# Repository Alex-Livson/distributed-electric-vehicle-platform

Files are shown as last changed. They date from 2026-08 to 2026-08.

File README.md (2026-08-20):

# Distributed Electric Vehicle Control and Autonomy Platform

A small-scale electric vehicle electronics platform built around **three custom ESP32-based ECUs and a Raspberry Pi 4 supervisory controller**, connected through a **500 kbps CAN network**.

The project was built as a hands-on study of automotive embedded systems, custom PCB design, distributed vehicle electronics, safety-oriented control, Raspberry Pi development, and computer vision.

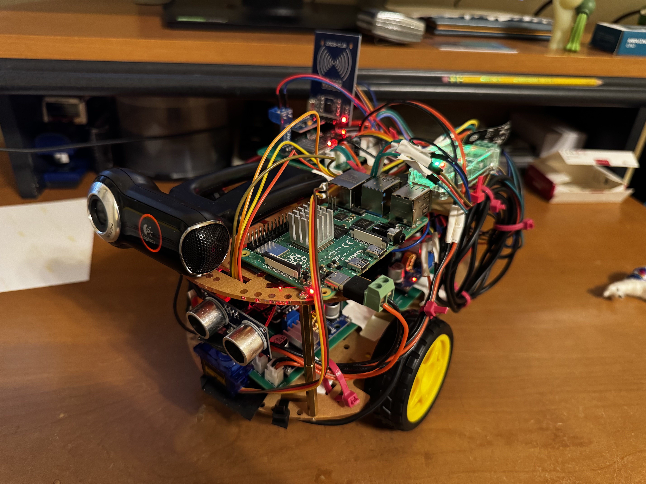
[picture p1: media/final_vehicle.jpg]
Final Vehicle


## Demo

[Watch the Vehicle Demo](https://youtu.be/MoWJwQRdX8E)

The demonstration includes manual driving, RFID authorization, assisted collision protection, live vehicle telemetry, and OpenCV-assisted autonomous obstacle avoidance.

---

## Project Overview

The vehicle uses a distributed control architecture similar in concept to a simplified electric vehicle.

Instead of one microcontroller handling the entire system, responsibilities are divided between several networked controllers:

* **Battery ECU** – monitors pack voltage, current, temperature, and battery health
* **Sensor ECU** – manages ultrasonic ranging, servo scanning, IMU telemetry, RFID authorization, OLED displays, and the LED matrix
* **Motor ECU** – controls the left and right drive motors
* **Raspberry Pi 4** – acts as the supervisory vehicle computer, hosts the dashboard, manages safety logic, processes CAN telemetry, and runs OpenCV perception

All four nodes communicate over a shared **500 kbps CAN bus**.

---

## Key Features

* Three custom ESP32 ECU PCBs designed in KiCad
* Four-node 500 kbps CAN network
* Raspberry Pi 4 supervisory vehicle controller
* Browser-based real-time vehicle dashboard
* Manual, Assisted, and Autonomous driving modes
* Whole-vehicle voltage, current, and temperature monitoring
* RFID-based vehicle authorization
* Ultrasonic obstacle detection with servo scanning
* OpenCV-assisted autonomous obstacle avoidance
* IMU acceleration, angular velocity, and orientation telemetry
* Differential motor control
* Emergency-stop functionality
* CAN and browser communication watchdogs
* Distance-based collision protection
* Multi-stage overcurrent protection
* Automatic Raspberry Pi and CAN startup

---

# System Architecture

The architecture separates sensing, power monitoring, motor actuation, and higher-level decision making.

```text
                         Raspberry Pi 4
                    Supervisory Vehicle Computer
                              │
                              │
                       500 kbps CAN Bus
                              │
          ┌───────────────────┼───────────────────┐
          │                   │                   │
     Battery ECU          Sensor ECU          Motor ECU
          │                   │                   │
     INA228 + NTC      Ultrasonic / IMU       TB6612FNG
                            RFID             Dual TT Motors
                         OLED Displays
                          LED Matrix
```

The Raspberry Pi receives telemetry from each ECU, applies supervisory safety rules, and transmits the final motor commands to the vehicle.

---

# Custom ECU Hardware

The electronics were first validated on breadboards and then converted into three custom two-layer PCBs.

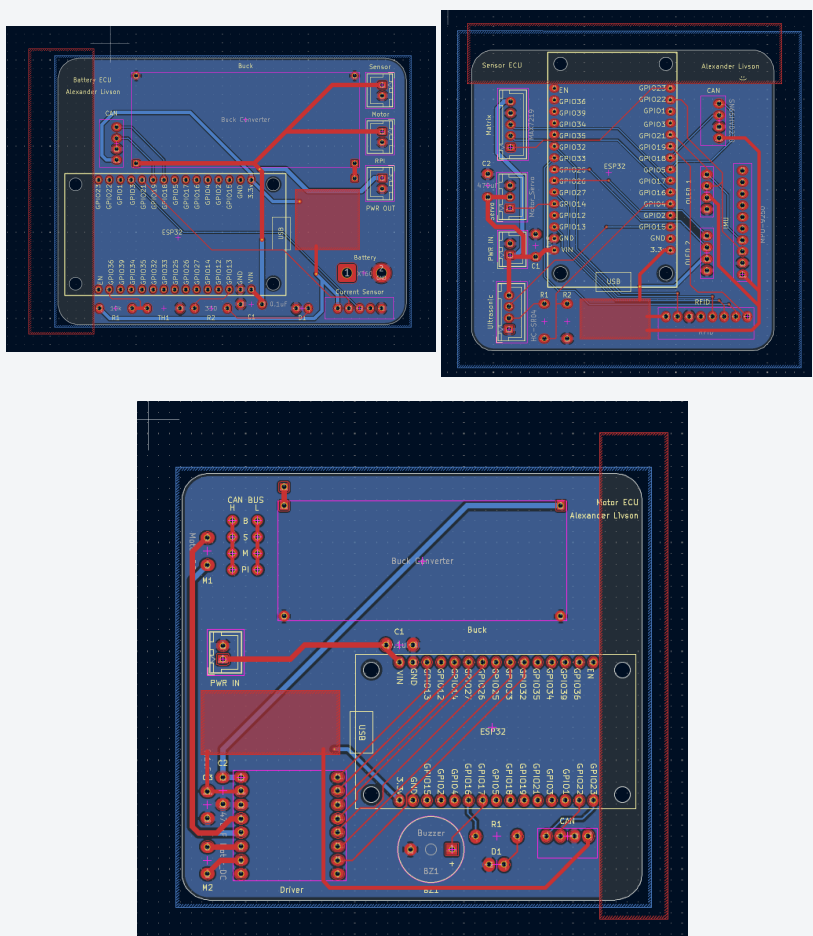
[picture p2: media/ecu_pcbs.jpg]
ECU PCBs


## Battery ECU

The Battery ECU monitors the electrical health of the complete vehicle.

Hardware includes:

* ESP32-WROOM-32 development board
* INA228 current and voltage monitor
* 10 kΩ NTC thermistor
* CAN transceiver
* Status LED
* Power-distribution connections

The INA228 is positioned near the beginning of the vehicle power path so current measurement represents the entire system.

---

## Sensor ECU

The Sensor ECU manages most of the vehicle's environmental sensing and local user interface.

It controls:

* HC-SR04 ultrasonic distance sensor
* Microservo for left/center/right scanning
* MPU9250 IMU
* MFRC522 RFID reader
* Two 0.96" 128×64 OLED displays
* MAX7219 8×8 LED matrix
* CAN communication

The ultrasonic sensor continuously provides forward and directional range data used by both the safety system and autonomous driving logic.

---

## Motor ECU

The Motor ECU controls two TT gearmotors through a **TB6612FNG dual motor driver**.

Commands are transmitted as independent signed left and right motor percentages, allowing:

* Forward driving
* Reverse driving
* Differential steering
* In-place turning

The ECU also reports motor status back to the Raspberry Pi over CAN.

---

# PCB Development

All three ECU boards were designed in **KiCad**.

The PCB development process included:

1. Breadboard hardware validation
2. Schematic capture
3. Custom through-hole footprint creation
4. Two-layer PCB layout
5. Ground-plane design
6. Power trace sizing
7. ESP32 antenna keep-out
8. Design Rule Check
9. Fabrication through JLCPCB
10. Hand soldering and hardware bring-up

Typical trace widths were approximately:

* **0.25 mm** for signals
* **0.75 mm** for 3.3 V distribution
* **1.0 mm** for higher-current 5 V paths

The bottom layer was used primarily as a ground plane.

---

# CAN Network

The completed vehicle contains four CAN nodes operating at **500 kbps**.

The Battery ECU and Raspberry Pi are located at the two ends of the physical bus and provide termination.

A powered-off measurement across CAN-H and CAN-L is approximately **60 Ω**, corresponding to two effective 120 Ω terminating resistors.

## CAN Message Map

| CAN ID  | Direction | Purpose |
| --- | --- | --- |
| `0x100` | Battery ECU → Pi | Battery voltage, current, and temperature |
| `0x200` | Sensor ECU → Pi  | Sensor status, ultrasonic range, RFID state |
| `0x201` | Sensor ECU → Pi  | Accelerometer X/Y/Z |
| `0x202` | Sensor ECU → Pi  | Angular velocity X/Y/Z |
| `0x203` | Sensor ECU → Pi  | Roll, pitch, and yaw |
| `0x204` | Sensor ECU → Pi  | Left, center, and right ultrasonic ranges |
| `0x300` | Motor ECU → Pi | Motor output and ECU status |
| `0x400` | Pi → Vehicle | Drive command, mode, speed limit, and safety state |
| `0x401` | Pi → Sensor ECU  | Lock/unlock request |

Detailed CAN payload definitions are available in the full engineering report.

---

# Raspberry Pi Vehicle Computer

The vehicle computer is a **Raspberry Pi 4 Model B with 1 GB RAM** running Raspberry Pi OS Lite.

The main controller is written in Python and integrates:

* Linux SocketCAN
* Flask
* OpenCV
* Threaded CAN reception
* Safety management
* Vehicle state tracking
* Autonomous decision making
* Browser control
* Camera streaming

The Pi runs a supervisory control loop every **20 ms**, corresponding to approximately **50 Hz**.

CAN and the main vehicle application are configured to initialize automatically when the Raspberry Pi boots.

---

# Web Dashboard

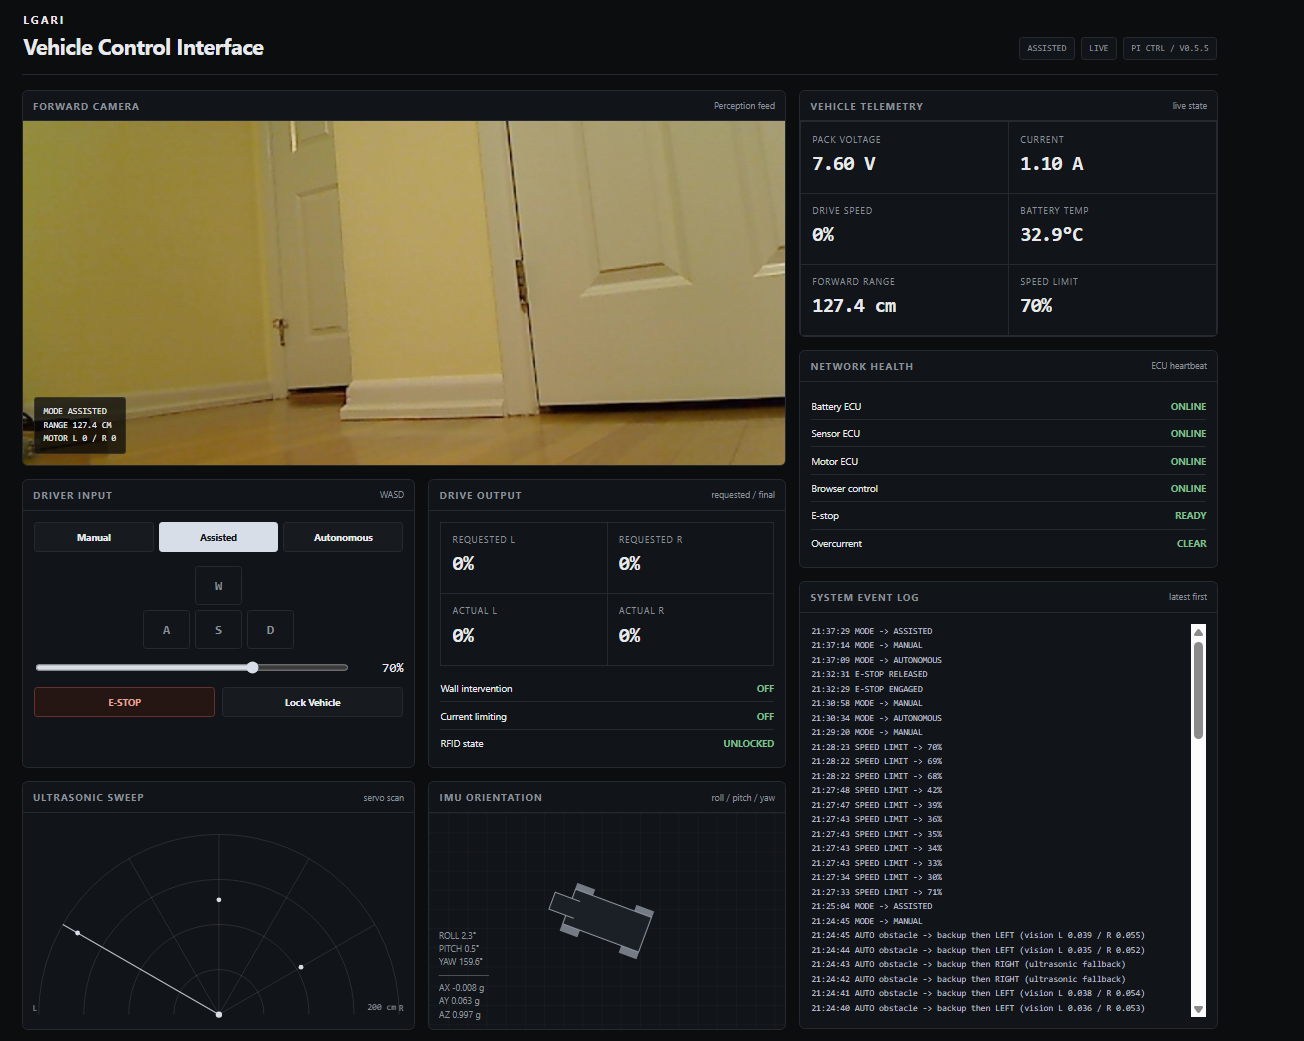
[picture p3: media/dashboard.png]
Vehicle Dashboard


The Raspberry Pi hosts a local browser-based vehicle interface.

The dashboard displays:

* Live forward camera
* Drive mode
* Motor requests and feedback
* Pack voltage
* Pack current
* Battery temperature
* Ultrasonic distance
* Ultrasonic radar visualization
* IMU orientation
* Acceleration
* ECU network health
* RFID lock state
* E-stop state
* Current limiting
* Wall intervention
* System event history

Manual and Assisted driving are controlled using **WASD**, with an adjustable 0–100% speed limit.

---

# Drive Modes

## Manual

Manual mode gives the driver direct WASD control over the differential drive system.

A forward collision stop remains active even in Manual mode so the vehicle cannot continue driving directly into a very close obstacle during testing.

---

## Assisted

Assisted mode keeps manual WASD control while adding distance-based collision protection.

| Forward Distance | Vehicle Response |
| --- | --- |
| Greater than 40 cm | Normal requested output |
| 20–40 cm | Forward output progressively reduced |
| 12–20 cm | Positive forward commands removed |
| Less than 12 cm | Hard forward collision intervention  |

This allows the driver to remain in control while the supervisory system limits unsafe commands.

---

## Autonomous

Autonomous mode combines **ultrasonic ranging and OpenCV computer vision**.

The ultrasonic sensor determines when an obstacle is physically close.

When an obstacle requires avoidance, OpenCV evaluates the left and right portions of the camera image to estimate which side appears less obstructed.

The vehicle then:

1. Detects the obstacle
2. Determines the clearer direction
3. Reverses briefly to create turning clearance
4. Turns toward the clearer side
5. Resumes forward driving

If the camera result is unavailable or nearly tied, the vehicle falls back to the left/right ultrasonic scan.

The system is intended as **vision-assisted obstacle avoidance**, rather than full autonomous driving or localization.

---

# OpenCV Perception

The OpenCV pipeline processes the lower portion of the forward camera image.

Processing includes:

* Grayscale conversion
* Gaussian blur
* Canny edge detection
* Edge dilation
* Left/right image segmentation
* Weighted edge-density comparison

The lower portion of each image region is weighted more heavily because it is more likely to contain obstacles in the vehicle's immediate path.

---

# Safety Architecture

All requested motor commands pass through a supervisory safety manager before being transmitted to the Motor ECU.

| Protection | Behavior |
| --- | --- |
| RFID authorization | Blocks vehicle movement while locked |
| Emergency stop | Overrides all drive modes |
| Browser watchdog | Stops Manual/Assisted control after 500 ms without fresh input |
| Battery ECU timeout  | Blocks motion if critical battery telemetry becomes stale |
| Sensor ECU timeout | Blocks motion if critical sensor telemetry becomes stale |
| Wall protection | Slows or stops forward movement near obstacles |
| Current warning | Reduces motor output above 4.75 A |
| Current limiting | Stronger output reduction above 5.25 A |
| Overcurrent shutdown | Stops vehicle above 5.50 A and applies a 1.5 s cooldown |

The system follows a fail-safe principle: if the controller does not have enough current information to determine that movement is safe, the preferred state is no movement.

---

# Final System Performance

| Metric | Result |
| --- | --- |
| CAN bitrate | 500 kbps |
| Pi supervisory loop | 50 Hz |
| Local browser control latency | ~20–30 ms |
| Idle current | ~0.8–0.9 A |
| Typical driving current | ~1.2–1.3 A |
| Peak observed current | ~1.6 A |
| Battery runtime | ~1 hour |
| Battery | 2S 7.4 V, 2000 mAh |
| Vehicle dimensions | 24 × 19 × 19 cm |
| Vehicle mass | ~872 g including battery |
| Estimated maximum speed | ~4 ft/s |
| Approximate project cost | ~$300 |

Maximum physical speed is estimated rather than encoder-measured because the current prototype does not contain wheel encoders.

---

# Full Engineering Report

A complete engineering report documents the project architecture, PCB development, electrical system, CAN protocol, software, safety design, debugging process, validation, and future improvements.

**[Read the full Engineering Report](docs/Engineering_Report.pdf)** (download pdf!)

---

# Project Development

The project was developed between **July 11 and August 17, 2026**.

I designed the system architecture, defined the ECU responsibilities and CAN protocol, created all three PCB schematics and layouts, assembled and soldered the boards, integrated the vehicle electronics, and performed final system testing.

The project uses standard hardware and software libraries for common peripheral interfaces and software functionality. Development also included external code review and troubleshooting assistance.

---

## Documentation

* **[Engineering Report](docs/Engineering_Report.pdf)**
* **[Vehicle Demonstration](https://youtu.be/MoWJwQRdX8E)**

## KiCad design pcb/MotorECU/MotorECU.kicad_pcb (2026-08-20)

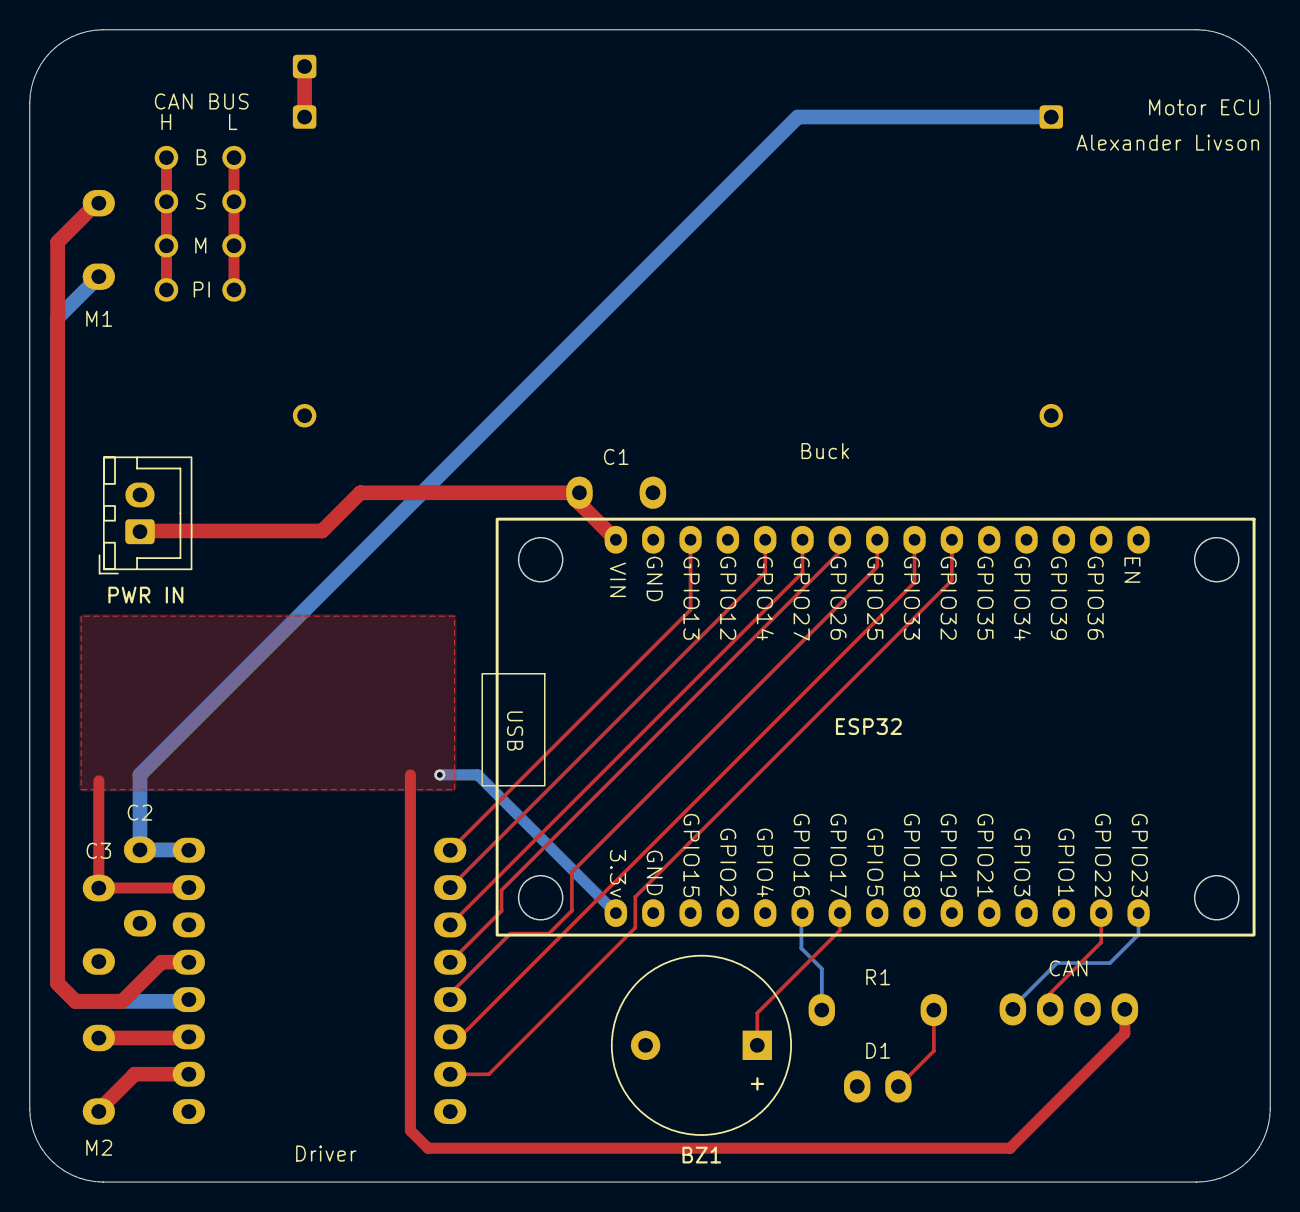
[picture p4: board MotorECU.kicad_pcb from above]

Board: 2 copper layers, 84.4 x 78.4 mm, 13 parts (0 on the bottom side), 20 nets.

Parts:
BZ1: Buzzer; Buzzer_12x9.5RM7.6
Buck: Buck Converter
C1, C3: 0.1uF; 0.1 Ceramic Capacitor
C2: 470uF; Elytrolytic Capacitor
CAN: SN65HVD230; SN65HVD230 CAN Module
D1: LED
Driver: TB6612FNG; TB6612FNG DC Motor Driver
ESP32: ESP32_30pin
M1, M2: Motor_DC; DC_Motor
PWR IN: JST_XH_B2B-XH-A_1x02_P2.50mm_Vertical
R1: 330; Resistor

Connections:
+3.3V: C3.1, CAN.1 (3.3V), Driver.2 (VCC), ESP32.16 (3.3v)
+5V: Buck.3 (OUT+), C2.1, Driver.1 (VM)
/5V_ESP: C1.1, ESP32.1 (VIN), PWR IN.1
/A1: Driver.4 (A1), M1.1 (+)
/A2: Driver.5 (A2), M1.2 (-)
/B1: Driver.6 (B1), M2.1 (+)
/B2: Driver.7 (B2), M2.2 (-)
GND: BZ1.2 (-), Buck.2 (IN-), Buck.4 (OUT-), C1.2, C2.2, C3.2, CAN.2 (GND), D1.1 (K), Driver.3 (GND), ESP32.2 (GND), PWR IN.2
unnamed: BZ1.1 (+), ESP32.22 (GPIO17)
unnamed: D1.2 (A), R1.2
unnamed: Driver.16 (PWMA), ESP32.3 (GPIO13)
unnamed: Driver.15 (AIN2), ESP32.5 (GPIO14)
unnamed: ESP32.21 (GPIO16), R1.1
unnamed: CAN.3 (CAN_RX), ESP32.29 (GPIO22)
unnamed: CAN.4 (CAN_TX), ESP32.30 (GPIO23)
unnamed: Driver.12 (BIN1), ESP32.8 (GPIO25)
unnamed: Driver.13 (STBY), ESP32.7 (GPIO26)
unnamed: Driver.14 (AIN1), ESP32.6 (GPIO27)
unnamed: Driver.10 (PWMB), ESP32.10 (GPIO32)
unnamed: Driver.11 (BIN2), ESP32.9 (GPIO33)

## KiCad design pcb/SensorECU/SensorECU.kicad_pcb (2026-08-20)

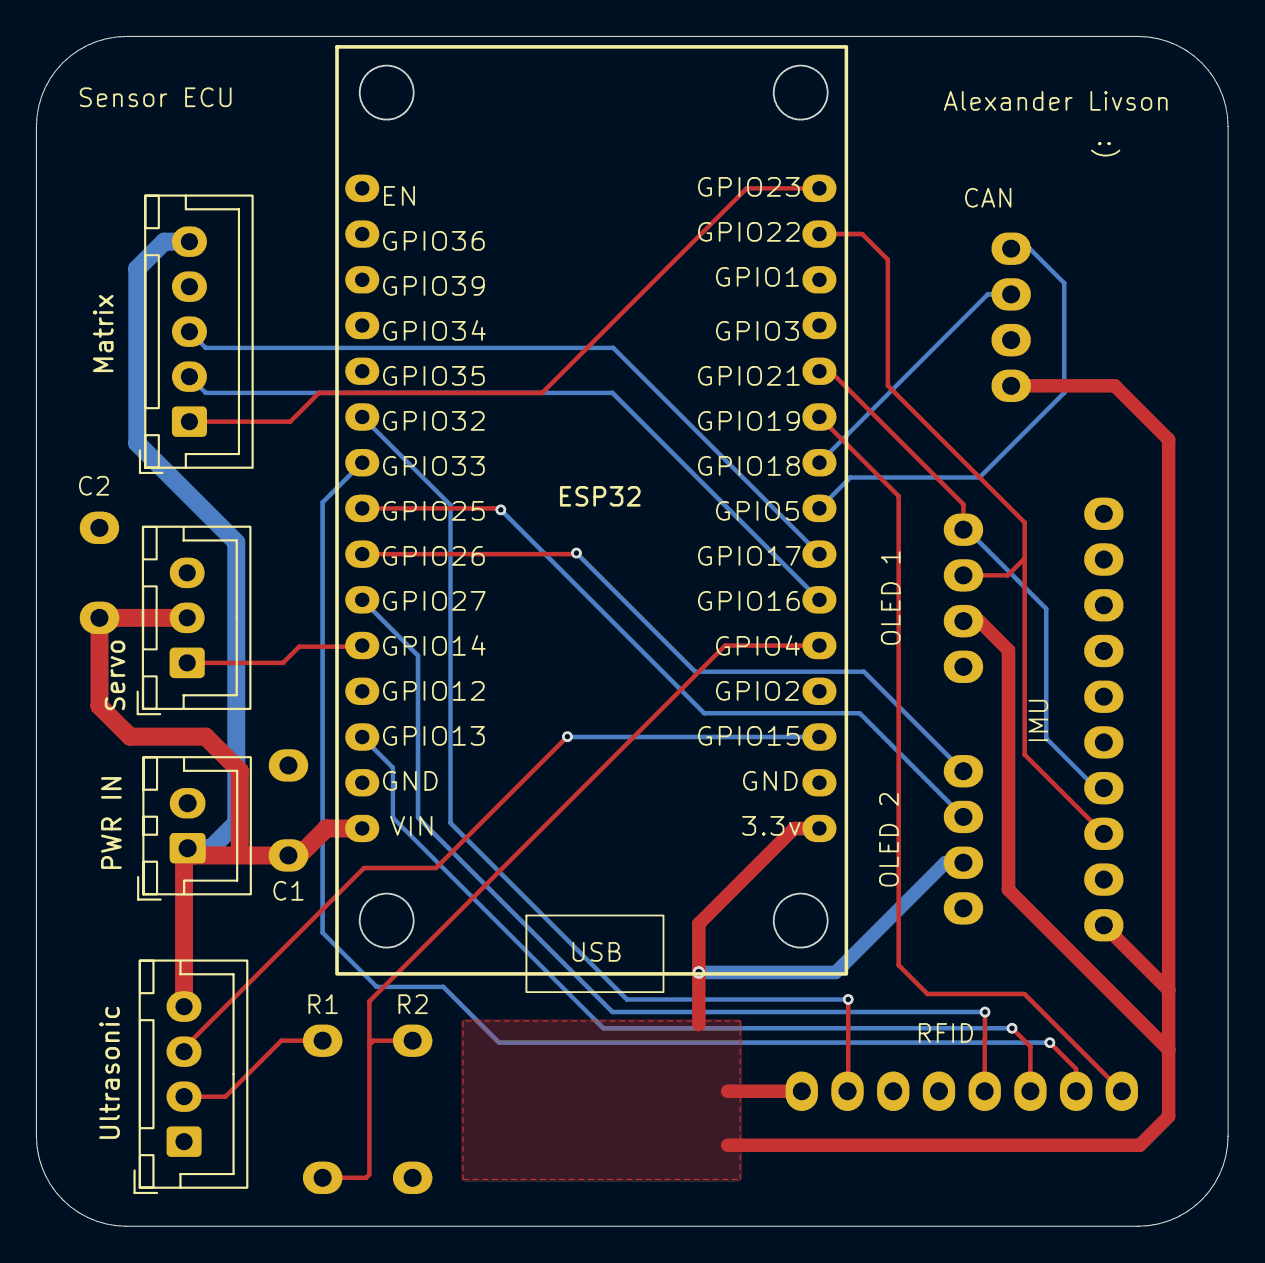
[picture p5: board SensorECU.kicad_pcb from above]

Board: 2 copper layers, 66.2 x 66.1 mm, 13 parts (0 on the bottom side), 21 nets.

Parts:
C1: 0.1uF; 0.1 Ceramic Capacitor
C2: 470uF; Elytrolytic Capacitor
CAN: SN65HVD230; SN65HVD230 CAN Module
ESP32: ESP32_30pin
IMU: MPU-9250; IMU_MPU-9250
Matrix: MAX7219; JST_XH_B5B-XH-A_1x05_P2.50mm_Vertical
OLED 1: OLED 1; 0.96 in. OLED
OLED 2: OLED 2; 0.96 in. OLED
R1: 1k; Resistor
R2: 2k; Resistor
RFID: RFID; RFID-RC522
Servo: Motor_Servo; JST_XH_B3B-XH-A_1x03_P2.50mm_Vertical
Ultrasonic: HC-SR04; JST_XH_B4B-XH-A_1x04_P2.50mm_Vertical

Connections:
+3.3V: CAN.1 (3.3V), ESP32.16 (3.3v), IMU.1 (VCC), OLED 1.2 (VCC), OLED 2.2 (VCC), RFID.8 (3.3V)
+5V: C1.1, C2.1, ESP32.1 (VIN), Matrix.5 (VCC), Servo.2 (+), Ultrasonic.4 (VCC)
/GPIO19: ESP32.25 (GPIO19), RFID.1 (SDA)
/PWM_Servo: ESP32.5 (GPIO14), Servo.1 (PWM)
/SCL_1: ESP32.29 (GPIO22), IMU.3 (SCL), OLED 1.3 (SCL)
/SCL_2: ESP32.8 (GPIO25), OLED 2.3 (SCL)
/SDA_1: ESP32.26 (GPIO21), IMU.4 (SDA), OLED 1.4 (SDA)
/SDA_2: ESP32.7 (GPIO26), OLED 2.4 (SDA)
GND: C1.2, C2.2, CAN.2 (GND), ESP32.2 (GND), IMU.2 (GND), Matrix.4 (GND), OLED 1.1 (GND), OLED 2.1 (GND), R2.2, RFID.6 (GND), Servo.3 (-), Ultrasonic.1 (GND)
unnamed: ESP32.20 (GPIO4), R1.2, R2.1
unnamed: CAN.4 (CAN_TX), ESP32.23 (GPIO5)
unnamed: ESP32.3 (GPIO13), RFID.3 (MOSI)
unnamed: ESP32.18 (GPIO15), Ultrasonic.3 (Trig)
unnamed: ESP32.21 (GPIO16), Matrix.2 (CS)
unnamed: ESP32.22 (GPIO17), Matrix.3 (DIN)
unnamed: CAN.3 (CAN_RX), ESP32.24 (GPIO18)
unnamed: ESP32.30 (GPIO23), Matrix.1 (CLK)
unnamed: ESP32.6 (GPIO27), RFID.4 (MISO)
unnamed: ESP32.10 (GPIO32), RFID.7 (RST)
unnamed: ESP32.9 (GPIO33), RFID.2 (SCK)
unnamed: R1.1, Ultrasonic.2 (Echo)

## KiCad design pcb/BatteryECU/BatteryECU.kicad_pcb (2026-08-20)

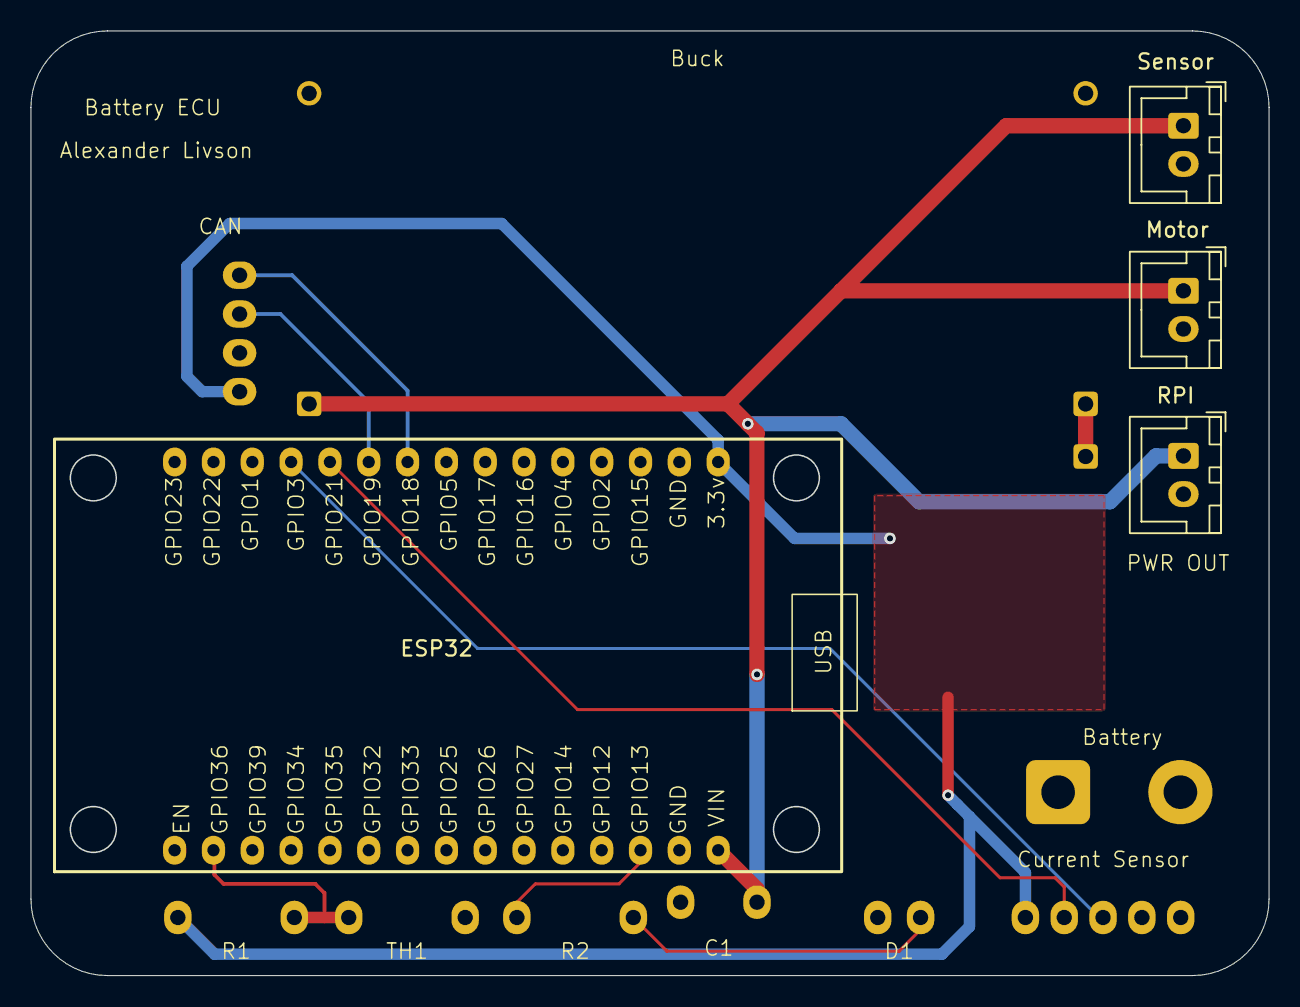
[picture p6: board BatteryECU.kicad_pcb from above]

Board: 2 copper layers, 81.0 x 61.8 mm, 13 parts (0 on the bottom side), 10 nets.

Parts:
Battery: XT60; Battery
Buck: Buck Converter
C1: 0.1uF; 0.1 Ceramic Capacitor
CAN: SN65HVD230; SN65HVD230 CAN Module
Current Sensor: INA228
D1: LED
ESP32: ESP32_30pin
Motor: JST_XH_B2B-XH-A_1x02_P2.50mm_Vertical
R1: 10k; Resistor
R2: 330; Resistor
RPI: JST_XH_B2B-XH-A_1x02_P2.50mm_Vertical
Sensor: JST_XH_B2B-XH-A_1x02_P2.50mm_Vertical
TH1: Thermistor_US; Thermistor

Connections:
+3.3V: CAN.1 (3.3V), Current Sensor.5 (VCC), ESP32.16 (3.3v), R1.1
+5V: Buck.3 (OUT+), C1.1, ESP32.1 (VIN), Motor.1, RPI.1, Sensor.1
/SCL: Current Sensor.3 (SCL), ESP32.27 (GPIO3)
/SDA: Current Sensor.4 (SDA), ESP32.26 (GPIO21)
GND: Battery.2, Buck.2 (IN-), Buck.4 (OUT-), C1.2, CAN.2 (GND), Current Sensor.1 (GND), D1.1 (K), ESP32.2 (GND), Motor.2, RPI.2, Sensor.2, TH1.2
unnamed: D1.2 (A), R2.2
unnamed: ESP32.3 (GPIO13), R2.1
unnamed: CAN.4 (CAN_TX), ESP32.24 (GPIO18)
unnamed: CAN.3 (CAN_RX), ESP32.25 (GPIO19)
unnamed: ESP32.14 (GPIO36), R1.2, TH1.1

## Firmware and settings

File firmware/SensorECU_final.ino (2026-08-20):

/*
  CAN bus:
    500 kbit/s, standard 11-bit IDs

  Sensor ECU -> Raspberry Pi:
    0x200 = range + servo + status
    0x201 = acceleration
    0x202 = gyro
    0x203 = roll/pitch/yaw
    0x204 = left/center/right scan

  Battery ECU -> Sensor ECU:
    0x100 = battery status, used for OLED #2

  Raspberry Pi -> Sensor ECU:
    0x400 = safety-filtered drive command, mode and E-stop status
            used for OLED #1 and MAX7219 direction arrows
    0x401 = browser vehicle lock/unlock command
*/

#include <Arduino.h>
#include <Wire.h>
#include <SPI.h>
#include <MFRC522.h>
#include <Adafruit_GFX.h>
#include <Adafruit_SSD1306.h>
#include <MD_MAX72xx.h>
#include <ESP32Servo.h>
#include <driver/twai.h>
#include <math.h>
#include <stdint.h>

// =====================================================
// USER SETTINGS
// =====================================================

const bool ENABLE_SERVO_SCAN = true;

bool vehicleUnlocked = false;
const uint8_t AUTHORIZED_RFID_UID[4] = {0x2D, 0xB9, 0xEC, 0x44};

// Change these if either OLED uses address 0x3D.
const uint8_t OLED1_ADDRESS = 0x3C;
const uint8_t OLED2_ADDRESS = 0x3C;

const uint8_t MPU_ADDRESS_PRIMARY = 0x68;
const uint8_t MPU_ADDRESS_SECONDARY = 0x69;

// =====================================================
// PIN DEFINITIONS
// =====================================================

const int SERVO_PIN = 14;

const int I2C1_SDA = 21;
const int I2C1_SCL = 22;

// OLED #2 uses its dedicated secondary I2C pins.
const int I2C2_SDA = 26;
const int I2C2_SCL = 25;

const int RFID_SS_PIN = 19;
const int RFID_SCK_PIN = 33;
const int RFID_MOSI_PIN = 13;
const int RFID_MISO_PIN = 27;
const int RFID_RST_PIN = 32;

const int ULTRASONIC_TRIG_PIN = 15;
const int ULTRASONIC_ECHO_PIN = 4;

const int MATRIX_DIN_PIN = 17;
const int MATRIX_CLK_PIN = 23;
const int MATRIX_CS_PIN = 16;

// SN65HVD230 CAN transceiver.
const gpio_num_t CAN_TX_PIN = GPIO_NUM_5;
const gpio_num_t CAN_RX_PIN = GPIO_NUM_18;

// =====================================================
// CAN PROTOCOL
// =====================================================

const uint32_t BATTERY_STATUS_CAN_ID = 0x100;

const uint32_t SENSOR_STATUS_CAN_ID      = 0x200;
const uint32_t SENSOR_ACCEL_CAN_ID       = 0x201;
const uint32_t SENSOR_GYRO_CAN_ID        = 0x202;
const uint32_t SENSOR_ORIENTATION_CAN_ID = 0x203;
const uint32_t SENSOR_SCAN_CAN_ID        = 0x204;
const uint32_t PI_DRIVE_COMMAND_CAN_ID = 0x400;
const uint32_t PI_LOCK_COMMAND_CAN_ID  = 0x401;

// Sensor telemetry is transmitted at 10 Hz.
// The Pi declares an ECU stale after 500 ms
const unsigned long CAN_TX_INTERVAL_MS = 100;

// =====================================================
// OLED CONFIGURATION
// =====================================================

const int SCREEN_WIDTH = 128;
const int SCREEN_HEIGHT = 64;
const int OLED_RESET_PIN = -1;

TwoWire I2C_BUS_1 = TwoWire(0);
TwoWire I2C_BUS_2 = TwoWire(1);

Adafruit_SSD1306 oled1(
  SCREEN_WIDTH,
  SCREEN_HEIGHT,
  &I2C_BUS_1,
  OLED_RESET_PIN
);

Adafruit_SSD1306 oled2(
  SCREEN_WIDTH,
  SCREEN_HEIGHT,
  &I2C_BUS_2,
  OLED_RESET_PIN
);

// =====================================================
// LED MATRIX CONFIGURATION
// =====================================================

#define MATRIX_HARDWARE_TYPE MD_MAX72XX::FC16_HW
#define MATRIX_DEVICE_COUNT 1

MD_MAX72XX matrix(
  MATRIX_HARDWARE_TYPE,
  MATRIX_DIN_PIN,
  MATRIX_CLK_PIN,
  MATRIX_CS_PIN,
  MATRIX_DEVICE_COUNT
);

// =====================================================
// RFID CONFIGURATION
// =====================================================

MFRC522 rfid(RFID_SS_PIN, RFID_RST_PIN);

bool rfidWorking = false;
unsigned long lastRfidReadTime = 0;
const unsigned long RFID_SCAN_COOLDOWN_MS = 900;

// =====================================================
// SERVO / ULTRASONIC SCAN CONFIGURATION
// =====================================================

Servo sensorServo;

const int SERVO_CENTER_DEG = 90;
const int SERVO_SCAN_LIMIT_DEG = 60;
const int SERVO_MIN_PULSE_US = 500;
const int SERVO_MAX_PULSE_US = 2400;

const unsigned long SERVO_POSITION_DWELL_MS = 700;
const unsigned long ULTRASONIC_TIMEOUT_US = 30000;

const int SERVO_SCAN_POSITIONS[] = {
  -SERVO_SCAN_LIMIT_DEG,
  0,
  SERVO_SCAN_LIMIT_DEG,
  0
};
const int SERVO_SCAN_POSITION_COUNT =
  sizeof(SERVO_SCAN_POSITIONS) / sizeof(SERVO_SCAN_POSITIONS[0]);

// Start centered. Index 1 corresponds to the CENTER entry above.
int servoScanPositionIndex = 1;
int servoScanAngleDeg = 0;

float latestInstantDistanceCm = NAN;
float scanLeftCm = NAN;
float scanCenterCm = NAN;
float scanRightCm = NAN;

// =====================================================
// MPU CONFIGURATION
// =====================================================

bool mpuWorking = false;
uint8_t detectedMpuAddress = 0;

float latestAxG = NAN;
float latestAyG = NAN;
float latestAzG = NAN;

float latestGxDps = NAN;
float latestGyDps = NAN;
float latestGzDps = NAN;

float latestRollDeg = 0.0f;
float latestPitchDeg = 0.0f;
float latestYawDeg = 0.0f;

bool imuFilterInitialized = false;
unsigned long previousImuMicros = 0;

const unsigned long IMU_UPDATE_INTERVAL_MS = 20; // 50 Hz.

// MPU full-scale settings used below:
// accel +/-2 g  -> 16384 LSB/g
// gyro  +/-250 dps -> 131 LSB/(deg/s)
const float ACCEL_LSB_PER_G = 16384.0f;
const float GYRO_LSB_PER_DPS = 131.0f;
const float COMPLEMENTARY_ALPHA = 0.98f;

// =====================================================
// DEVICE / CAN STATUS
// =====================================================

bool oled1Working = false;
bool oled2Working = false;
bool canWorking = false;

// Battery ECU data shown on OLED #2.
bool batteryMessageReceived = false;
float canBatteryVoltageV = NAN;
float canBatteryTemperatureC = NAN;
float canBatteryCurrentMa = NAN;
uint16_t batteryCanMessageCounter = 0;
unsigned long lastBatteryCanMessageTime = 0;
const unsigned long BATTERY_CAN_TIMEOUT_MS = 2000;

// One burst counter is shared by 0x200-0x204 so a receiver can associate
// the five frames from the same telemetry update.
uint16_t sensorCanCounter = 0;
uint32_t canTxFailureCount = 0;

// Latest safety-filtered Raspberry Pi drive command (CAN 0x400).
bool piDriveCommandReceived = false;
int8_t piDriveLeft = 0;
int8_t piDriveRight = 0;
uint8_t piDriveMode = 1;       // 0=MANUAL, 1=ASSISTED, 2=AUTONOMOUS
uint8_t piSpeedLimit = 0;
bool piEstopActive = false;
uint8_t piSafetyFlags = 0;
uint16_t piDriveCounter = 0;
unsigned long lastPiDriveCommandTime = 0;
const unsigned long PI_COMMAND_TIMEOUT_MS = 500;

// Latest Raspberry Pi browser lock command (CAN 0x401).
bool piLockCommandReceived = false;
uint16_t piLockCommandCounter = 0;
unsigned long lastPiLockCommandTime = 0;

// =====================================================
// TIMING
// =====================================================

unsigned long previousCanTxTime = 0;
unsigned long previousServoScanTime = 0;
unsigned long previousDisplayTime = 0;
unsigned long previousSerialStatusTime = 0;

const unsigned long DISPLAY_UPDATE_INTERVAL_MS = 250;
const unsigned long SERIAL_STATUS_INTERVAL_MS = 1000;

// =====================================================
// GENERAL HELPERS
// =====================================================

float clampFloat(float value, float lo, float hi) {
  if (value < lo) return lo;
  if (value > hi) return hi;
  return value;
}

float normalizeAngle180(float angleDeg) {
  while (angleDeg >= 180.0f) angleDeg -= 360.0f;
  while (angleDeg < -180.0f) angleDeg += 360.0f;
  return angleDeg;
}

uint16_t centimetersToMillimetersU16(float distanceCm) {
  if (isnan(distanceCm) || distanceCm < 0.0f) {
    return UINT16_MAX;
  }

  float mm = clampFloat(distanceCm * 10.0f, 0.0f, 65534.0f);
  return static_cast<uint16_t>(lroundf(mm));
}

int16_t floatToScaledI16(float value, float scale) {
  if (isnan(value)) {
    return INT16_MIN;
  }

  float scaled = value * scale;
  scaled = clampFloat(scaled, -32767.0f, 32767.0f);
  return static_cast<int16_t>(lroundf(scaled));
}

void putU16LE(uint8_t *data, int offset, uint16_t value) {
  data[offset] = static_cast<uint8_t>(value & 0xFF);
  data[offset + 1] = static_cast<uint8_t>((value >> 8) & 0xFF);
}

void putI16LE(uint8_t *data, int offset, int16_t value) {
  uint16_t raw = static_cast<uint16_t>(value);
  putU16LE(data, offset, raw);
}


int8_t decodeI8(uint8_t value) {
  return static_cast<int8_t>(value);
}

bool piCommandFresh() {
  return piDriveCommandReceived &&
         (millis() - lastPiDriveCommandTime <= PI_COMMAND_TIMEOUT_MS);
}

bool servoScanShouldBeActive() {
  return ENABLE_SERVO_SCAN &&
         piCommandFresh() &&
         piDriveMode != 0;
}

const char *driveModeName() {
  switch (piDriveMode) {
    case 0: return "MANUAL";
    case 2: return "AUTO";
    default: return "ASSISTED";
  }
}

int displayedDriveSpeedPercent() {
  if (!piCommandFresh() || !vehicleUnlocked || piEstopActive) {
    return 0;
  }

  int speed = (abs(static_cast<int>(piDriveLeft)) + abs(static_cast<int>(piDriveRight))) / 2;
  return constrain(speed, 0, 100);
}

const char *vehicleStatusName() {
  if (piEstopActive) {
    return "E-BRAKE";
  }

  bool batteryFresh = batteryMessageReceived && (millis() - lastBatteryCanMessageTime <= BATTERY_CAN_TIMEOUT_MS);

  if (!canWorking || !rfidWorking || !piCommandFresh() ||
      !batteryFresh || piSafetyFlags != 0 || !mpuWorking) {
    return "ERROR";
  }

  return "NORMAL";
}

int estimateBatteryPercent(float packVoltageV) {
  if (isnan(packVoltageV)) {
    return -1;
  }

  // Approximate 2S LiPo state-of-charge from resting pack voltage.
  // Under load the displayed percentage may temporarily sag.
  const float perCell = packVoltageV / 2.0f;

  struct SocPoint { float v; int pct; };
  static const SocPoint table[] = {
    {4.20f, 100}, {4.15f, 95}, {4.11f, 90}, {4.08f, 85},
    {4.02f, 80},  {3.98f, 75}, {3.95f, 70}, {3.91f, 65},
    {3.87f, 60},  {3.85f, 55}, {3.84f, 50}, {3.82f, 45},
    {3.80f, 40},  {3.79f, 35}, {3.77f, 30}, {3.75f, 25},
    {3.73f, 20},  {3.71f, 15}, {3.69f, 10}, {3.61f, 5},
    {3.20f, 0}
  };

  if (perCell >= table[0].v) return 100;
  if (perCell <= table[20].v) return 0;

  for (size_t i = 0; i < 20; i++) {
    if (perCell <= table[i].v && perCell >= table[i + 1].v) {
      float fraction = (perCell - table[i + 1].v) /
                       (table[i].v - table[i + 1].v);
      float pct = table[i + 1].pct +
                  fraction * (table[i].pct - table[i + 1].pct);
      return constrain(static_cast<int>(lroundf(pct)), 0, 100);
    }
  }

  return 0;
}

// =====================================================
// I2C HELPERS
// =====================================================

bool pingI2CDevice(TwoWire &bus, uint8_t address) {
  bus.beginTransmission(address);
  return bus.endTransmission() == 0;
}

void scanI2CBus(TwoWire &bus, const char *busName) {
  Serial.println();
  Serial.print("Scanning ");
  Serial.println(busName);

  int deviceCount = 0;

  for (uint8_t address = 1; address < 127; address++) {
    bus.beginTransmission(address);
    uint8_t error = bus.endTransmission();

    if (error == 0) {
      Serial.print("  Found device at 0x");
      if (address < 0x10) Serial.print("0");
      Serial.println(address, HEX);
      deviceCount++;
    }
  }

  if (deviceCount == 0) {
    Serial.println("  No I2C devices found.");
  } else {
    Serial.print("  Total devices found: ");
    Serial.println(deviceCount);
  }
}

bool writeI2CRegister(
  TwoWire &bus,
  uint8_t deviceAddress,
  uint8_t registerAddress,
  uint8_t value
) {
  bus.beginTransmission(deviceAddress);
  bus.write(registerAddress);
  bus.write(value);
  return bus.endTransmission() == 0;
}

bool readI2CRegister(
  TwoWire &bus,
  uint8_t deviceAddress,
  uint8_t registerAddress,
  uint8_t &result
) {
  bus.beginTransmission(deviceAddress);
  bus.write(registerAddress);

  if (bus.endTransmission(false) != 0) {
    return false;
  }

  uint8_t bytesReceived = bus.requestFrom(
    deviceAddress,
    static_cast<uint8_t>(1)
  );

  if (bytesReceived != 1) {
    return false;
  }

  result = bus.read();
  return true;
}

// =====================================================
// MPU
// =====================================================

bool detectMPU() {
  uint8_t whoAmI = 0;

  const uint8_t possibleAddresses[] = {
    MPU_ADDRESS_PRIMARY,
    MPU_ADDRESS_SECONDARY
  };

  for (uint8_t address : possibleAddresses) {
    if (!pingI2CDevice(I2C_BUS_1, address)) {
      continue;
    }

    if (!readI2CRegister(I2C_BUS_1, address, 0x75, whoAmI)) {
      continue;
    }

    Serial.print("MPU WHO_AM_I at 0x");
    Serial.print(address, HEX);
    Serial.print(": 0x");
    Serial.println(whoAmI, HEX);

    if (
      whoAmI == 0x71 ||
      whoAmI == 0x73 ||
      whoAmI == 0x70 ||
      whoAmI == 0x68
    ) {
      detectedMpuAddress = address;
      return true;
    }
  }

  detectedMpuAddress = 0;
  return false;
}

bool initializeMPU() {
  if (!detectMPU()) {
    return false;
  }

  // Wake device.
  if (!writeI2CRegister(I2C_BUS_1, detectedMpuAddress, 0x6B, 0x00)) {
    return false;
  }
  delay(100);

  // DLPF enabled, approximately 44 Hz gyro bandwidth.
  writeI2CRegister(I2C_BUS_1, detectedMpuAddress, 0x1A, 0x03);

  // Gyro +/-250 deg/s.
  writeI2CRegister(I2C_BUS_1, detectedMpuAddress, 0x1B, 0x00);

  // Accelerometer +/-2 g.
  writeI2CRegister(I2C_BUS_1, detectedMpuAddress, 0x1C, 0x00);

  // Accel DLPF where supported by MPU6500/9250.
  writeI2CRegister(I2C_BUS_1, detectedMpuAddress, 0x1D, 0x03);

  previousImuMicros = micros();
  imuFilterInitialized = false;
  return true;
}

int16_t readBigEndianI16(TwoWire &bus) {
  uint8_t highByte = static_cast<uint8_t>(bus.read());
  uint8_t lowByte = static_cast<uint8_t>(bus.read());

  return static_cast<int16_t>(
    (static_cast<uint16_t>(highByte) << 8) |
    static_cast<uint16_t>(lowByte)
  );
}

bool readMPUData() {
  if (!mpuWorking) {
    return false;
  }

  // ACCEL_XOUT_H through GYRO_ZOUT_L = 14 bytes.
  I2C_BUS_1.beginTransmission(detectedMpuAddress);
  I2C_BUS_1.write(0x3B);

  if (I2C_BUS_1.endTransmission(false) != 0) {
    return false;
  }

  uint8_t bytesReceived = I2C_BUS_1.requestFrom(
    detectedMpuAddress,
    static_cast<uint8_t>(14)
  );

  if (bytesReceived != 14) {
    return false;
  }

  int16_t axRaw = readBigEndianI16(I2C_BUS_1);
  int16_t ayRaw = readBigEndianI16(I2C_BUS_1);
  int16_t azRaw = readBigEndianI16(I2C_BUS_1);

  // Temperature is not used by the vehicle app.
  (void)readBigEndianI16(I2C_BUS_1);

  int16_t gxRaw = readBigEndianI16(I2C_BUS_1);
  int16_t gyRaw = readBigEndianI16(I2C_BUS_1);
  int16_t gzRaw = readBigEndianI16(I2C_BUS_1);

  latestAxG = axRaw / ACCEL_LSB_PER_G;
  latestAyG = ayRaw / ACCEL_LSB_PER_G;
  latestAzG = azRaw / ACCEL_LSB_PER_G;

  latestGxDps = gxRaw / GYRO_LSB_PER_DPS;
  latestGyDps = gyRaw / GYRO_LSB_PER_DPS;
  latestGzDps = gzRaw / GYRO_LSB_PER_DPS;

  float accelRollDeg = atan2f(
    latestAyG,
    latestAzG
  ) * 180.0f / PI;

  float accelPitchDeg = atan2f(
    -latestAxG,
    sqrtf(latestAyG * latestAyG + latestAzG * latestAzG)
  ) * 180.0f / PI;

  unsigned long currentMicros = micros();
  float dt = (currentMicros - previousImuMicros) / 1000000.0f;
  previousImuMicros = currentMicros;

  // Protect the filter from a giant step after a pause/debugger stop.
  if (dt <= 0.0f || dt > 0.25f) {
    dt = IMU_UPDATE_INTERVAL_MS / 1000.0f;
  }

  if (!imuFilterInitialized) {
    latestRollDeg = accelRollDeg;
    latestPitchDeg = accelPitchDeg;
    latestYawDeg = 0.0f;
    imuFilterInitialized = true;
  } else {
    latestRollDeg =
      COMPLEMENTARY_ALPHA * (latestRollDeg + latestGxDps * dt) +
      (1.0f - COMPLEMENTARY_ALPHA) * accelRollDeg;

    latestPitchDeg =
      COMPLEMENTARY_ALPHA * (latestPitchDeg + latestGyDps * dt) +
      (1.0f - COMPLEMENTARY_ALPHA) * accelPitchDeg;

    // MPU6500 has no usable magnetometer heading in this configuration,
    // so yaw is gyro-integrated and can slowly drift over time.
    latestYawDeg = normalizeAngle180(
      latestYawDeg + latestGzDps * dt
    );
  }

  return true;
}

void updateIMU() {
  static unsigned long lastImuUpdateMs = 0;

  if (millis() - lastImuUpdateMs < IMU_UPDATE_INTERVAL_MS) {
    return;
  }

  lastImuUpdateMs = millis();

  if (!readMPUData()) {
    latestAxG = NAN;
    latestAyG = NAN;
    latestAzG = NAN;
    latestGxDps = NAN;
    latestGyDps = NAN;
    latestGzDps = NAN;
  }
}

// =====================================================
// ULTRASONIC / SERVO SCAN
// =====================================================

float readUltrasonicDistanceCm() {
  digitalWrite(ULTRASONIC_TRIG_PIN, LOW);
  delayMicroseconds(3);

  digitalWrite(ULTRASONIC_TRIG_PIN, HIGH);
  delayMicroseconds(10);

  digitalWrite(ULTRASONIC_TRIG_PIN, LOW);

  unsigned long echoDuration = pulseIn(
    ULTRASONIC_ECHO_PIN,
    HIGH,
    ULTRASONIC_TIMEOUT_US
  );

  if (echoDuration == 0) {
    return NAN;
  }

  return echoDuration * 0.0343f / 2.0f;
}

void initializeServoScan() {
  if (!ENABLE_SERVO_SCAN) {
    servoScanAngleDeg = 0;
    Serial.println("Ultrasonic servo scan disabled.");
    return;
  }

  sensorServo.setPeriodHertz(50);
  sensorServo.attach(
    SERVO_PIN,
    SERVO_MIN_PULSE_US,
    SERVO_MAX_PULSE_US
  );

  // Always boot centered. The servo will only begin sweeping after a fresh
  // ASSISTED or AUTONOMOUS drive command is received from the Raspberry Pi.
  servoScanPositionIndex = 1;
  servoScanAngleDeg = 0;
  sensorServo.write(SERVO_CENTER_DEG);
  delay(700);

  Serial.println("Ultrasonic servo initialized on GPIO 14.");
  Serial.println("  MANUAL: centered");
  Serial.println("  ASSISTED/AUTONOMOUS: scanning");
}

void storeScanReading(int angleDeg, float distanceCm) {
  latestInstantDistanceCm = distanceCm;

  if (isnan(distanceCm)) {
    return;
  }

  if (!ENABLE_SERVO_SCAN) {
    scanCenterCm = distanceCm;
    return;
  }

  // The scan positions pass exactly through -60, 0, and +60 degrees.
  if (angleDeg == -SERVO_SCAN_LIMIT_DEG) {
    scanLeftCm = distanceCm;
  } else if (angleDeg == 0) {
    scanCenterCm = distanceCm;
  } else if (angleDeg == SERVO_SCAN_LIMIT_DEG) {
    scanRightCm = distanceCm;
  }
}

void updateServoScan() {
  static bool wasScanning = false;

  bool shouldScan = servoScanShouldBeActive();

  // MANUAL mode, stale Pi command, or globally disabled scan:
  // keep the servo centered and continue measuring straight ahead.
  if (!shouldScan) {
    if (ENABLE_SERVO_SCAN &&
        (wasScanning || servoScanAngleDeg != 0)) {
      servoScanPositionIndex = 1;
      servoScanAngleDeg = 0;
      sensorServo.write(SERVO_CENTER_DEG);

      // Left/right values came from an earlier scan and should not be treated
      // as current while the vehicle is in centered MANUAL operation.
      scanLeftCm = NAN;
      scanRightCm = NAN;

      // Give the servo a full dwell period to settle at center before taking
      // the next forward range measurement.
      previousServoScanTime = millis();
    }

    wasScanning = false;

    if (millis() - previousServoScanTime < SERVO_POSITION_DWELL_MS) {
      return;
    }

    previousServoScanTime = millis();

    float distanceCm = readUltrasonicDistanceCm();
    storeScanReading(0, distanceCm);
    return;
  }

  if (!wasScanning) {
    wasScanning = true;
    servoScanPositionIndex = 1;
    servoScanAngleDeg = 0;
    sensorServo.write(SERVO_CENTER_DEG);
    previousServoScanTime = millis();
    return;
  }

  if (millis() - previousServoScanTime < SERVO_POSITION_DWELL_MS) {
    return;
  }

  previousServoScanTime = millis();

  // The servo has been sitting still at this position for the full dwell interval, so take the ultrasonic reading before commanding another move.
  float distanceCm = readUltrasonicDistanceCm();
  storeScanReading(servoScanAngleDeg, distanceCm);

  // Advance through CENTER -> RIGHT -> CENTER -> LEFT -> CENTER -> repeat.
  servoScanPositionIndex =
    (servoScanPositionIndex + 1) % SERVO_SCAN_POSITION_COUNT;

  servoScanAngleDeg = SERVO_SCAN_POSITIONS[servoScanPositionIndex];

  // Only one new target command is issued per dwell interval.
  sensorServo.write(SERVO_CENTER_DEG + servoScanAngleDeg);
}

// =====================================================
// RFID
// =====================================================

bool authorizedUidPresent() {
  if (rfid.uid.size != 4) {
    return false;
  }

  MFRC522::PICC_Type cardType = rfid.PICC_GetType(rfid.uid.sak);
  if (cardType != MFRC522::PICC_TYPE_MIFARE_1K) {
    return false;
  }

  for (byte i = 0; i < 4; i++) {
    if (rfid.uid.uidByte[i] != AUTHORIZED_RFID_UID[i]) {
      return false;
    }
  }

  return true;
}

void initializeRFID() {

  SPI.begin(
    RFID_SCK_PIN,
    RFID_MISO_PIN,
    RFID_MOSI_PIN,
    RFID_SS_PIN
  );

  rfid.PCD_Init(RFID_SS_PIN, RFID_RST_PIN);
  delay(50);

  byte version = rfid.PCD_ReadRegister(MFRC522::VersionReg);
  rfidWorking = (version != 0x00 && version != 0xFF);

  Serial.print("MFRC522 version register: 0x");
  if (version < 0x10) Serial.print("0");
  Serial.println(version, HEX);

  if (rfidWorking) {
    Serial.println("RFID reader online. Authorized UID: 2D:B9:EC:44");
  } else {
    Serial.println("ERROR: MFRC522 communication failed. Vehicle remains locked.");
  }
}
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
void loop() {
  processCanMessages();
  updateRFID();

  updateIMU();
  updateServoScan();
  updateMatrixDirection();

  sendSensorCanBurst();

  updateDisplays();
  printSerialStatus();
}

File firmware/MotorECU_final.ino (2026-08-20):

/*
  CAN bus:
    500 kbit/s, standard 11-bit IDs

  Raspberry Pi -> Motor ECU, CAN 0x400:
    byte 0: left motor command, signed int8, -100..100 %
    byte 1: right motor command, signed int8, -100..100 %
    byte 2: drive mode
            0 = MANUAL
            1 = ASSISTED
            2 = AUTONOMOUS
    byte 3: speed limit, uint8, 0..100 %
    byte 4: flags
            bit0 = E-stop active
            bit1 = vehicle unlocked
    byte 5: safety flags
            bit0 = wall intervention active
            bit1 = current intervention active
            bit2 = overcurrent fault active
    byte 6-7: rolling uint16 command counter, little-endian

  Motor ECU -> Raspberry Pi, CAN 0x300:
    byte 0: applied left output, signed int8 %
    byte 1: applied right output, signed int8 %
    byte 2: motor driver enabled, 0/1
    byte 3: Motor ECU fault flags
            bit0 = Pi command timeout / no command
            bit1 = E-stop active
            bit2 = vehicle locked
            bit3 = overcurrent fault
            bit4 = CAN driver unavailable
    byte 4-5: rolling uint16 status counter, little-endian
    byte 6-7: reserved
*/

#include <Arduino.h>
#include <driver/twai.h>
#include <stdint.h>

// ============================================================
// PIN ASSIGNMENTS
// ============================================================

// Status outputs
const int LED_PIN    = 16;
const int BUZZER_PIN = 17;

// TB6612FNG
// Motor A = LEFT motor
const int PWMA_PIN = 13;
const int AIN2_PIN = 14;
const int AIN1_PIN = 27;
const int STBY_PIN = 26;

// Motor B = RIGHT motor
const int BIN1_PIN = 25;
const int BIN2_PIN = 33;
const int PWMB_PIN = 32;

// SN65HVD230 CAN transceiver
const gpio_num_t CAN_TX_PIN = GPIO_NUM_23;
const gpio_num_t CAN_RX_PIN = GPIO_NUM_22;

// ============================================================
// CAN PROTOCOL
// ============================================================

const uint32_t MOTOR_STATUS_CAN_ID     = 0x300;
const uint32_t PI_DRIVE_COMMAND_CAN_ID = 0x400;

const unsigned long MOTOR_STATUS_INTERVAL_MS = 100;

const unsigned long PI_COMMAND_TIMEOUT_MS = 500;

// ============================================================
// PWM / MOTOR SETTINGS
// ============================================================

const int MOTOR_PWM_FREQUENCY = 20000;
const int PWM_RESOLUTION = 8;
const int PWM_MAX = 255;

// Normal commands are ramped to reduce abrupt starts and reversals.
// 10 percentage points every 20 ms:
//   0 -> 50% in about 100 ms
//   0 -> 100% in about 200 ms
// Safety stops are always immediate.
const unsigned long MOTOR_RAMP_INTERVAL_MS = 20;
const int MOTOR_RAMP_STEP_PERCENT = 10;

// ============================================================
// CAN / COMMAND STATE
// ============================================================

bool canWorking = false;

bool piCommandReceived = false;
unsigned long lastPiCommandTime = 0;

int8_t requestedLeftPercent = 0;
int8_t requestedRightPercent = 0;

int appliedLeftPercent = 0;
int appliedRightPercent = 0;

uint8_t piDriveMode = 1;
uint8_t piSpeedLimit = 0;

bool piEstopActive = false;
bool vehicleUnlocked = false;

bool wallIntervention = false;
bool currentIntervention = false;
bool overcurrentFault = false;

uint16_t piCommandCounter = 0;
uint16_t motorStatusCounter = 0;

bool motorDriverEnabled = false;

unsigned long previousMotorRampTime = 0;
unsigned long previousStatusTxTime = 0;
unsigned long previousSerialTime = 0;

bool previousEstopActive = false;
bool previousOvercurrentFault = false;

bool buzzerActive = false;
unsigned long buzzerStartTime = 0;
unsigned long buzzerDurationMs = 0;

// ============================================================
// SMALL HELPERS
// ============================================================

int clampPercent(int value) {
  if (value > 100) return 100;
  if (value < -100) return -100;
  return value;
}

int decodeI8(uint8_t value) {
  return (value > 127)
    ? static_cast<int>(value) - 256
    : static_cast<int>(value);
}

uint8_t encodeI8(int value) {
  value = clampPercent(value);
  return static_cast<uint8_t>(static_cast<int8_t>(value));
}

void putU16LE(uint8_t data[8], int offset, uint16_t value) {
  data[offset]     = static_cast<uint8_t>(value & 0xFF);
  data[offset + 1] = static_cast<uint8_t>((value >> 8) & 0xFF);
}

bool piCommandFresh() {
  if (!piCommandReceived) {
    return false;
  }

  return (millis() - lastPiCommandTime) <= PI_COMMAND_TIMEOUT_MS;
}

const char* driveModeName() {
  switch (piDriveMode) {
    case 0: return "MANUAL";
    case 1: return "ASSISTED";
    case 2: return "AUTONOMOUS";
    default: return "UNKNOWN";
  }
}

// ============================================================
// BUZZER
// ============================================================
//
// Active buzzer:
//   GPIO17 HIGH = buzzer ON
//   GPIO17 LOW  = buzzer OFF
//
// No PWM/tone generation is needed because the active buzzer contains
// its own oscillator.

void silenceBuzzer() {
  buzzerActive = false;
  buzzerDurationMs = 0;

  digitalWrite(BUZZER_PIN, LOW);
}

void startBuzzer(unsigned long durationMs) {
  buzzerActive = true;
  buzzerStartTime = millis();
  buzzerDurationMs = durationMs;

  digitalWrite(BUZZER_PIN, HIGH);
}

void updateBuzzer() {
  if (!buzzerActive) {
    digitalWrite(BUZZER_PIN, LOW);
    return;
  }

  if (millis() - buzzerStartTime >= buzzerDurationMs) {
    silenceBuzzer();
  }
}

// ============================================================
// TB6612FNG MOTOR OUTPUT
// ============================================================

int percentToPwm(int percent) {
  int magnitude = abs(clampPercent(percent));
  return (magnitude * PWM_MAX) / 100;
}

void writeMotorA(int percent) {
  percent = clampPercent(percent);
  int pwm = percentToPwm(percent);

  if (percent > 0) {
    // Preserve the verified bench-test Motor A forward direction.
    digitalWrite(AIN1_PIN, LOW);
    digitalWrite(AIN2_PIN, HIGH);
    ledcWrite(PWMA_PIN, pwm);
  }
  else if (percent < 0) {
    digitalWrite(AIN1_PIN, HIGH);
    digitalWrite(AIN2_PIN, LOW);
    ledcWrite(PWMA_PIN, pwm);
  }
  else {
    ledcWrite(PWMA_PIN, 0);
    digitalWrite(AIN1_PIN, LOW);
    digitalWrite(AIN2_PIN, LOW);
  }
}

void writeMotorB(int percent) {
  percent = clampPercent(percent);
  int pwm = percentToPwm(percent);

  if (percent > 0) {
    digitalWrite(BIN1_PIN, HIGH);
    digitalWrite(BIN2_PIN, LOW);
    ledcWrite(PWMB_PIN, pwm);
  }
  else if (percent < 0) {
    digitalWrite(BIN1_PIN, LOW);
    digitalWrite(BIN2_PIN, HIGH);
    ledcWrite(PWMB_PIN, pwm);
  }
  else {
    ledcWrite(PWMB_PIN, 0);
    digitalWrite(BIN1_PIN, LOW);
    digitalWrite(BIN2_PIN, LOW);
  }
}

void setMotorDriverEnabled(bool enabled) {
  motorDriverEnabled = enabled;
  digitalWrite(STBY_PIN, enabled ? HIGH : LOW);
}
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
